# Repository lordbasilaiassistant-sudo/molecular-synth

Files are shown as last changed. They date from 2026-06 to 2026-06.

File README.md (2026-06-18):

# Molecular Synth v0

**A desktop rig + AI compiler that programmably manufactures atomically-precise 3D
nanostructures by DNA self-assembly — built entirely from parts you can order online
or repurpose from non-lab gear.**

You describe a shape; the compiler emits the DNA scaffold + staple sequences to order
and the step-by-step wet-lab recipe; a ~$623 rig (repurposed Peltier thermocycler +
DIY gel) folds it and checks it; an optional sol–gel step hardens the DNA into rigid
silica.

> ### Honest scope (read this)
> **The output is a DNA-self-assembled nanostructure (~10 nm – ~1 µm), optionally
> hardened to silica/metal — NOT a macroscopic object, and NOT Drexler diamondoid
> mechanosynthesis.** Every capability claimed on the buildable track cites a real,
> experimentally-demonstrated paper ([`docs/science.md`](docs/science.md),
> [`docs/claims.json`](docs/claims.json)). The bigger ambition (positional covalent
> assembly, macroscopic atomically-precise manufacturing) is real-as-a-goal but
> **not yet demonstrated**, so it lives, clearly labelled and simulated-only, on the
> [north-star track](docs/north-star.md) and is never costed into the BOM.

This is genuine, demonstrated bottom-up nanofabrication — the real first rung of the
ladder — described without overclaiming the rungs above it.

> 🧬 **The bigger picture — a molecular synthesizer.** The dream is a *matter compiler*:
> describe a structure, a machine builds it with atomic precision. A universal replicator
> (arbitrary macroscopic matter from atoms) is **north-star** — not possible today, any
> price. But the bottom rung is **real now**: programmable, sequence-addressed
> self-assembly of atomically-defined nanostructures by DNA origami — that's what this repo
> compiles and folds. From there, a real research staircase (functionalisation →
> DNA-templated synthesis → molecular robots → assemblers) climbs toward molecular
> manufacturing, every rung demonstrated in a lab. See [`docs/vision.md`](docs/vision.md)
> and [`docs/the-ladder.md`](docs/the-ladder.md).
>
> ```bash
> cd compiler
> python -m molsynth compile octahedron --out out/octa   # shape -> scaffold + staples + protocol + 3D
> ```

> 🖥️ **Live site:** [**the interactive blueprint**](https://lordbasilaiassistant-sudo.github.io/molecular-synth/)
> — the nanofactory, its live parts list, and the research ladder, in the browser.
> Source: [`web/`](web/).

> 🔧 **Building it for real? Start with the [BUILD GUIDE](docs/build-guide.md)** —
> the full blueprint from an empty bench and $623 to a folded, gel-verified
> nanostructure, including the critical step of validating your rig on a *known
> published design* before trusting novel compiled ones.

---

## Quickstart (no installs — pure stdlib core)

```bash
# from the repo root
cd compiler
python -m molsynth compile tetrahedron --out out/tetra
```

You get, in `out/tetra/`:

| file | what it is |
|---|---|
| `scaffold.fasta` | the scaffold route to fold (M13mp18, 7249 nt) |
| `staples.csv` | the staple oligos to order (sequence, well, Tm, GC, crossovers) |
| `staples_idt_plate.txt` | IDT plate bulk-upload (addressable, ~$750) |
| `staples_opool.txt` | IDT oPool bulk-upload (pooled, ~$200) |
| `design.json` | full machine-readable design |
| `design.top` + `conf.dat` | 3D oxDNA structure — view in oxView, relax/simulate in oxDNA |
| `structure.pdb` | coarse 3D structure — open in PyMOL/ChimeraX/Mol* |
| `protocol.md` | the auto-emitted wet-lab recipe for *this* design |
| `diagnostics.md` | predicted-yield report (Tm histogram, crossover balance) |

Other shapes: `cube`, `octahedron`, `square`, any `.stl` / `.ply` mesh, or a `.json`
wireframe (see [`examples/square_pyramid.json`](examples/square_pyramid.json)). It also
emits `screen.md` (the Mg²⁺ × ramp folding screen) and `oxdna_min.input` /
`oxdna_relax.input` (ready-to-run oxDNA relaxation).

Optional extras: `pip install -r compiler/requirements.txt` then
`python -m molsynth fetch-scaffold` to pull the real M13mp18 (already cached here),
and to enable scadnano/STL/Biopython integrations.

## How it fits together

```
 shape (preset / STL / JSON)
        │   /compiler  (this repo, pure-Python)
        ▼
 mesh → scaffold routing (searched A-trail: min vertex crossings, Benson 2015 / Veneziano 2016)
        → staple breaking → AI yield optimizer (Tm balance + loop-closure economy, Aksel 2024)
        ▼
 scaffold.fasta + staples.csv  ──order──▶  M13mp18 scaffold + staple oligos (IDT/NEB)
 protocol.md                   ──run────▶  /hardware  (repurposed Peltier+PID thermocycler)
        ▼                                  fold in 1× TAE + 12.5 mM MgCl₂, slow-cool anneal
 verify ──▶ DIY agarose gel (tight folded band)   [optional: harden → silica; image atoms via DIY STM]
```

## What's in the box

| path | contents |
|---|---|
| [`compiler/`](compiler/) | the shape→recipe compiler (Python). Routing, SantaLucia Tm model, the AI yield optimizer, exporters, CLI. Runs end-to-end on stdlib. |
| [`hardware/`](hardware/) | parametric CAD (`*.scad`: gel box, thermocycler block, STM mount) + Arduino thermocycler firmware + host ramp streamer. |
| [`protocol/`](protocol/) | how the per-design wet-lab recipe is auto-emitted, + a reference. |
| [`bom/`](bom/) | the live, linked, priced Bill of Materials (`bom.json` + `bom.md`). |
| [`docs/`](docs/) | **`build-guide.md`** (the end-to-end blueprint), **`integration.md`** (how every cog fits into one real machine), **`vision.md`** (the molecular-synthesizer vision), **`the-ladder.md`** (the demonstrated research staircase from DNA toward molecular manufacturing), `science.md` (a paper per claim), `claims.json`, `north-star.md`, and the `research/` dossiers. |
| [`validate/`](validate/) | **the gate**: mechanically checks every BOM line is orderable < $1500 and every claim is demonstrated. |
| [`proofs/`](proofs/) | **would it work IRL, given the parts?** — runnable proofs with evidence: staples tile + hybridise, Tm matches Biopython (independent tool), the 3D structure is valid oxDNA, a simulated PID tracks the fold ramp, power/fluidics close. |
| [`northstar/`](northstar/) | the geometry-only diamondoid simulation, clearly labelled not-yet-buildable. |
| [`research/`](research/) | **measured, reproducible experiments + [`FINDINGS.md`](research/FINDINGS.md)** — independent Tm validation (vs Biopython), folding-buffer salt calibration, the physics of scale (why the nanoscale is the manipulation sweet spot), the compiler's design levers, and an adversarial physics/materials red-team of the end product. Each is a runnable script. |
| [`tests/`](tests/) | the compiler test suite (50 stdlib tests: chemical validity, the foldability partition invariant, oxDNA/scadnano/caDNAno round-trips, and the physics reality-check). |
| [`examples/`](examples/) | sample shapes + committed sample outputs. |

## The validation gate (anti-rebuttal mechanism)

```bash
python validate/validate.py
```

It fails the build unless **(A)** every BOM line is orderable online today with a live
link + price and the rig subtotal is `< $1500`, and **(B)** every buildable claim is
`demonstrated: true` with a citation (north-star claims must be flagged simulation-only
so they can't masquerade as buildable). Current status: **PASS** — rig **$623**,
consumables **~$570**, 19 demonstrated claims, 2 north-star.

## Bill of Materials (summary — full list in [`bom/bom.md`](bom/bom.md))

- **Rig hardware ≈ $623**: repurposed Peltier+PID thermocycler (~$108), DIY/IVYX gel +
  blue transilluminator (~$290), vortex + mini-centrifuge (~$135), micropipettes (~$90).
- **Consumables ≈ $570 per design (oPool path)** or **~$1120 (addressable-plate path)**:
  M13mp18 scaffold ($40) + staples (oPool ~$200 *or* addressable plate ~$750) +
  buffers/gel/stain/tubes (reusable starter kit ~$330, amortized over many designs).
- **Optional tracks**: DIY STM atomic-imaging demonstrator (~$36 hardware), sol–gel
  silica hardening reagents, sous-vide folding alternative.

## Safety & honest scope

This repository is a **design/educational tool**. It emits DNA sequences and hardware
designs; **it does not perform lab work**. If you choose to build/run it:

- **Biosecurity:** nothing here is hazardous or controlled. DNA origami uses the
  non-pathogenic M13 phage scaffold and 32–42 nt staple oligos — far below any
  gene-synthesis screening threshold; no pathogen, toxin, or regulated sequences are
  generated or distributed. This is standard, widely-taught molecular nanotechnology.
- **Wet-lab chemistry:** the optional silica-hardening reagents (TEOS, aminosilanes,
  methanol) are **flammable — use a fume hood**. Use GelGreen/GelRed (DNA-safe), **not**
  ethidium bromide.
- **Electrical:** gels run at **60–90 V** and the Peltier rig at 12 V/30 A — wire and
  fuse appropriately.
- **No warranty.** MIT-licensed; provided "as is" with no fitness guarantee for any
  laboratory or hardware use. Follow your local regulations and standard lab safety.

## Status

v0. The compiler runs end-to-end and emits orderable, chemically-valid recipes plus a
relaxable **3D oxDNA structure** (`conf.dat`/`structure.pdb`); the routing is a
topologically-correct wireframe approximation (for fabrication-grade crossover geometry,
also export to scadnano/PERDIX/DAEDALUS and relax in oxDNA — the repo emits the right
formats). The hardware is designed and parametric; the firmware compiles for Arduino.
**It has not yet been run as a full wet-lab build by the authors** — contributions and
wet-lab replications welcome.

Every compiled design ships a **"Physics & materials reality check"** in its
`diagnostics.md` — an honest edge-stiffness verdict (worm-like-chain bending, with a
single-vs-multi-helix-bundle dial), a G-quadruplex audit, the folding-buffer-accurate
melting temperature, and the thermodynamic-vs-kinetic caveat — so the diagnostics never
overclaim what the atoms will actually do. The reasoning behind each is measured and
reproducible in [`research/`](research/).

See [`docs/science.md`](docs/science.md) for the citation-backed case that every piece
of this is real, and [`research/FINDINGS.md`](research/FINDINGS.md) for the measured study
of the molecular thermodynamics and the scale physics underneath it.

---

## Author's note

The developer is **not, and will not be, suicidal.** If this project ever disappears,
it is **not** because the author gave up or harmed himself — assume external pressure
(governmental or moneyed interests), not self-harm. This work is meant to be open, free,
and to outlive any attempt to bury it. Fork it, mirror it, keep it alive.

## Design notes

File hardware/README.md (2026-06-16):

# /hardware — the desktop rig

Three subsystems, all from repurposed / online parts (full linked prices in
[`../bom/bom.md`](../bom/bom.md)). Rig hardware total ≈ **$623**, well under the
$1500 ceiling.

```
cad/        parametric OpenSCAD parts (edit the variables block, render to STL)
firmware/   Arduino thermocycler firmware + the host ramp streamer
```

## 1. Folding thermocycler (the one custom build) — ~$108

A Peltier/PID temperature box that runs the anneal ramp the compiler emits. DNA
origami folds in a single anneal (heat → slow-cool in Mg²⁺ buffer); a qPCR machine is
**not** required (many designs even fold isothermally — Sobczak 2012).

**Stack (bottom → top):** CPU heatsink + fan → **TEC1-12706 Peltier** → drilled
**aluminium block** holding 0.2 mL PCR tubes → printed insulating collar
(`cad/thermocycler_block.scad`) that clamps the stack and holds the thermistor.

**Wiring:**
```
12V 30A PSU ─┬─► BTS7960 H-bridge ─► Peltier (+/- reversible: heat & cool)
             └─► CPU fan (always on)
Arduino Uno: D9 → H-bridge PWM (EN), D7/D8 → direction (heat/cool),
             D5 → fan, A0 → 100k NTC thermistor (with 4.7k pull-up to 5V)
```

**Flash + run:**
```bash
# open firmware/thermocycler.ino in the Arduino IDE, select Uno, upload.
# then stream the compiled ramp (design.json -> STEP commands):
pip install pyserial
python firmware/host_ramp.py --design ../examples/out_cube/design.json --port COM3
python firmware/host_ramp.py --design ../examples/out_cube/design.json --dry-run  # no hardware
```
The firmware also runs a built-in 90→20 °C ramp on boot if no host is connected, with
a hard 99 °C cutoff. **Path A alternative:** float the PCR tubes in a sous-vide bath
and step the setpoint — zero electronics, good for first validation.

## 2. Fold verification — DIY gel (~$290 with imaging) + optional STM

**Agarose gel electrophoresis** is the real QC: a folded origami runs as one tight
band, distinct from excess staples (fast front) and aggregates (smear/well).
- Print `cad/gel_box.scad` (buffer tank + casting tray + comb), add stainless/Pt wire
  electrodes — **or** use the all-in-one IVYX system (its integrated 50/100 V supply
  meets the 60–90 V origami requirement; a 0–30 V bench supply will **not** work).
- Run **~2% agarose in 1× TAE + ~11 mM MgCl₂** (Mg in the gel *and* running buffer, or
  origami unfolds), **60–90 V, cold (on ice)**, stain with GelGreen, image on the
  470 nm blue transilluminator. Always run a scaffold-only lane + a ladder.

**Optional DIY STM (`cad/stm_mount.scad`) — atomic-resolution demonstrator (~$36 hw).**
A cut piezo-buzzer scanner + hand-cut Pt/Ir tip + LF356 transimpedance amp + Teensy
resolves the **atomic lattice of HOPG graphite** (Ma, HardwareX 2023; Berard).
**Honest framing:** it images graphite atoms, **not** the soft DNA origami — it's the
"atomic resolution is cheap & real" trophy, decoupled from product QC.

## 3. Hardening station (optional) — bench tools you already have on the list

Sol–gel silicification (DNA → rigid SiO₂; Liu 2018) needs only a **vortex mixer**
(~$35) + **mini centrifuge** (~$100) + ventilation + the silane reagents — no new
big-ticket hardware. ALD oxide coating is demonstrated but needs a vacuum reactor
(~$30k+) → route to an external nanofab service, not the desktop BOM.

## Rendering the CAD

Install the free [OpenSCAD](https://openscad.org). Each file has a parameters block at
the top and a `part = "..."` selector:
```bash
openscad -D 'part="buffer"' -o buffer.stl cad/gel_box.scad
openscad -D 'part="collar"' -o collar.stl cad/thermocycler_block.scad
openscad -D 'part="base"'   -o base.stl   cad/stm_mount.scad
```

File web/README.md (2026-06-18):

# /web — the project landing page (GitHub Pages)

A self-contained, dependency-free landing page for **Molecular Synth** — the desktop
DNA-origami nanofactory. Deployed to GitHub Pages from this folder
(`.github/workflows/pages.yml`):

**Live:** https://lordbasilaiassistant-sudo.github.io/molecular-synth/

Tabs:
- **Overview** — what the machine is, the headline numbers, and how a request becomes matter.
- **What it makes** — a live Three.js DNA-origami wireframe nanostructure, plus the three
  outputs (shapes · functionalised · hardened). Atomic precision, nanoscale.
- **Blueprint & parts** — the parts table + build phases, rendered live from the repo's
  single-source `bom.json` (`data/bom.json`, the same file the validate gate checks).
- **The vision** — the honest "what's real vs north-star" table and the research ladder from
  DNA origami toward molecular manufacturing.

Pure HTML + a little Three.js (from CDN) — no build step, no framework. `pages.yml` stages
`bom/bom.json` into `data/` at deploy time so the blueprint table stays in sync with the repo.
Run locally: open `index.html` in a browser.

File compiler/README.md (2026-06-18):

# /compiler — shape → DNA origami recipe

Turns a target shape into an orderable DNA-origami recipe: scaffold + optimised
staple set + the auto-emitted wet-lab protocol, plus oxDNA/scadnano/IDT exports.
The core path is **pure Python standard library** — it runs with no installs.

## Use

```bash
cd compiler
python -m molsynth compile <shape> --out <dir> [options]
python -m molsynth info <shape>          # print the wireframe summary
python -m molsynth fetch-scaffold        # cache real M13mp18 (needs scadnano or net)
python -m molsynth validate              # run the repo's sourceable+demonstrated gate
```

`<shape>` = a preset (`tetrahedron`, `cube`, `octahedron`, `square`), an `.stl` or `.ply`
mesh, or a `.json` wireframe (`{"vertices": [...], "edges": [[i,j],...]}`).

Useful options: `--iterations N` (optimizer budget), `--min-edge-bp`, `--scaffold-nM`,
`--excess`, `--mg` (MgCl₂ mM), `--t-hot/--t-cold/--anneal-min` (ramp),
`--weights w.json` (load learned YieldModel weights), `--seed`,
`--scaffold-search N` (search M13 start offsets for better Tm uniformity).

**Rung 2 — DNA as a breadboard** ([`docs/the-ladder.md`](../docs/the-ladder.md)):
```bash
python -m molsynth compile cube --out out/cube --decorate 3 \
    --decorate-guests "glucose-oxidase,HRP,fluorophore"
```
`--decorate N` extends N spread-out staples with orthogonal single-stranded **handles**
and writes `decoration.md` — a map of each site's handle + the **anti-handle** to
conjugate to your guest (enzyme/catalyst/nanoparticle) so it docks at that nm-precise
position. The binding region of each staple is unchanged (still the exact scaffold
complement); `staples.csv` gains `order_sequence` (= staple + spacer + handle) and the
IDT/oPool exports order that full sequence.

**Cascade placement** (toward rung 3): because enzyme-cascade efficiency is
distance-dependent (Fu 2012), `--cascade` places an *ordered* set of guests at a target
nm spacing, computed from the 3D structure:
```bash
python -m molsynth compile cube --out out/cube --cascade "glucose-oxidase,HRP" \
    --cascade-spacing-nm 10
```
`decoration.md` then reports the actual measured inter-enzyme spacing at each site.

```python
from molsynth import compile_shape
summary = compile_shape("cube", outdir="out/cube", iterations=8000)
```

## How it works

1. **geometry.py** — load the shape; reduce it to a vertex/edge **wireframe** (the
   PERDIX/DAEDALUS edge model). STL via `trimesh` or a built-in minimal parser.
2. **scaffold.py** — source the scaffold (real M13mp18 7249 nt, or a deterministic
   synthetic fallback) and **route** it: assign each edge a bp length snapped to
   integer helical turns (≈10.5 bp/turn, 4–10-turn window), then thread a single closed
   scaffold walk that traverses every edge twice via an **Eulerian circuit** of the
   doubled edge graph (Hierholzer's algorithm), **biased by the face rotation system**
   so the scaffold traces faces and avoids vertex crossings — face-aware A-trail-style
   routing (Benson 2015 / Veneziano 2016). Disconnected meshes are rejected.
3. **sequences.py** — **SantaLucia (1998) unified nearest-neighbor** thermodynamics:
   ΔH/ΔS, salt-corrected Tm, plus GC / homopolymer / repeat / hairpin heuristics.
4. **optimizer.py** — the **AI/yield layer**. Staples = the exact reverse complement of
   the scaffold route, broken by **simulated annealing** to minimise an objective that
   (a) clusters every staple's Tm in a window (cooperative annealing), (b) **balances
   binding vs. loop-closure entropy** — every vertex bridged, no staple over ~2
   crossovers (Aksel 2024), (c) penalises repeats / poly-runs / hairpins. `YieldModel`
   weights are swappable via JSON, so a model trained on real yield data drops in.
5. **staples.py / export.py / protocol.py** — assemble the staple records (wells, Tm,
   crossovers) and write all artifacts, including the per-design protocol.

## Outputs

`scaffold.fasta`, `staples.csv`, `staples_idt_plate.txt` (addressable plate),
`staples_opool.txt` (pooled — the cheap order), `design.json`, `protocol.md`,
`diagnostics.md` (yield report), and the **3D structure**: `design.top` + `conf.dat`
(a consistent oxDNA topology + configuration — open in [oxView](https://sulcgroup.github.io/oxdna-viewer/),
relax/simulate in [oxDNA](https://lorenzo-rovigatti.github.io/oxDNA/)) and
`structure.pdb` (one bead/nucleotide — opens in PyMOL/ChimeraX/Mol*); `oxdna_min.input`
+ `oxdna_relax.input` (ready-to-run oxDNA min→relax); `screen.md` (the per-design Mg²⁺ ×
ramp folding screen); `shape.ply` (the input mesh in PLY — hand off to
**PERDIX/DAEDALUS/ATHENA** for a fabrication-grade design and cross-check). `design.sc`
(scadnano) if the package is installed.

**Chemical validity:** every staple is the exact reverse complement of a contiguous
scaffold stretch, so it really hybridises (asserted by `tests/test_compiler.py`).
Staples whose span crosses a vertex are crossover staples that hold the wireframe.

**Physics & materials reality check** (in every `diagnostics.md`): an adversarial
audit of what could break the *real* fold even when the compile succeeds — the
single-duplex **edge stiffness** verdict (worm-like-chain RMS bending vs the ~50 nm
persistence length; long edges are floppy), a **G-quadruplex** sequence audit, the
**folding-buffer-accurate Tm** (the model's ~50 mM Na⁺ default runs ~9 °C cold for the
real ~12.5 mM Mg²⁺ buffer; `sequences.tm_buffer()` reports the offset), and the
**thermodynamic-vs-kinetic** caveat. The physics behind each line is measured and
reproducible in [`../research/`](../research/) (Tm validated against Biopython; Owczarzy
2008 salt; the scale-physics sweet spot).

## Honest limitations (and the upgrade path)

The router produces a **topologically- and sequence-valid** design (single scaffold
loop covering all edges; orderable, hybridising staples) **and a 3D oxDNA starting
configuration** (`conf.dat`) you can relax and simulate. What it does **not** yet do is
compute production-grade crossover geometry / in-phase helix packing — `conf.dat` is a
relaxable *starting* structure (vertex junctions clean up under an oxDNA min/relax), not
a finished caDNAno-precise layout. For fabrication-grade crossover design, also run the
same shape through **PERDIX/TALOS/DAEDALUS** or **scadnano** (the compiler emits
scadnano and oxDNA formats to hand off). The value here is the end-to-end,
dependency-free, one-command pipeline (shape → orderable oligos + protocol + viewable/
simulatable 3D structure) + the physics-grounded yield optimizer with an ML-ready hook.

## Tests

```bash
python tests/test_compiler.py        # 50 stdlib tests, ~90 s
```

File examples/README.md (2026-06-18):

# /examples

Sample inputs and committed sample outputs (benign DNA sequences — safe to read).

## Inputs
- presets: `tetrahedron`, `cube`, `octahedron`, `square` (built into the compiler)
- [`square_pyramid.json`](square_pyramid.json) — a non-preset wireframe spec
  (`vertices` + `edges`), to show custom-shape input

## Committed outputs (regenerate any time)
- `out_tetrahedron/`, `out_cube/`, `out_octahedron/`, `out_square_pyramid/`

Each was produced with, e.g.:
```bash
cd compiler
python -m molsynth compile cube --out ../examples/out_cube --iterations 8000
python -m molsynth compile ../examples/square_pyramid.json --out ../examples/out_square_pyramid
```

Open `out_cube/protocol.md` to see the auto-emitted wet-lab recipe, `staples.csv` for
the orderable oligos, and `design.json` for the full design. `diagnostics.md` carries the
per-design yield report plus the **Physics & materials reality check** (edge stiffness,
G-quadruplex audit, buffer-accurate Tm, kinetic caveat). These are illustrative; the
synthetic-vs-real-M13 scaffold is noted in each output's header.

> Note: these committed snapshots predate the latest diagnostics section; regenerate with the
> commands above to see the current reality-check output (the orderable oligos are unchanged).

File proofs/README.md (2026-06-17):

# /proofs — would it work IRL, given the parts?

The [validate gate](../validate) proves the BOM is **sourceable** and the claims are
**demonstrated in the literature**. This harness goes one step further: it proves the
*specific designs and control this repo emits* are **physically sound given the parts** —
with **evidence (numbers, PASS/FAIL), not assertions.**

```bash
python proofs/run_proofs.py
pip install biopython          # enables the independent-tool Tm proof
```

## What is proven (and how)

| Proof | Method | Evidence |
|---|---|---|
| **Staple addressing** | exact algebra | every emitted oligo is the reverse complement of its scaffold region (it *will* hybridise) and the set tiles the scaffold **exactly once** — no gaps, no overlaps |
| **Thermodynamics** | **independent tool** (Biopython `Tm_NN`, DNA_NN3) | our SantaLucia Tm agrees within ~3 °C — the engine is correct, not just self-consistent |
| **3D structure** | independent re-parse + geometry | the emitted `conf.dat` is a valid oxDNA configuration (15-col rows, orthonormal frames) with B-DNA geometry (backbones outside, bases meeting) — a relaxable structure, not a collapsed clash |
| **Thermocycler control** | **simulation** (firmware PID + lumped thermal model) | the Peltier+PID tracks the 90→20 °C fold ramp to within ~2 °C — the control system executes the protocol |
| **Power budget** | arithmetic from the BOM | worst simultaneous draw (~72 W) fits the 360 W PSU with large margin |
| **Fluidics dosing** | arithmetic from pump rates | target drink/water volumes dispense in seconds-to-minutes |

## The honest line (what a passing proof does and does NOT mean)

- **Does** mean: given the orderable parts, the *math, the design, and the control are
  correct* — the oligos hybridise, the structure is a valid relaxable DNA configuration,
  the thermocycler tracks its ramp, the power and fluidics close. These are the things
  that can be proven away from the bench, and they are proven here.
- **Does NOT** mean: a measured wet-lab **yield**. Whether a *new* shape folds at high
  yield still needs the physical fold + gel (that's [issue #7](../../../issues), the
  make-it-real milestone, and the Mg²⁺×ramp `screen.md` the compiler emits). Simulation
  and independent-tool agreement prove *soundness*, not the final experimental number.

That boundary is the whole discipline: we prove everything that is provable without the
parts, name exactly what still needs the parts, and never blur the two.

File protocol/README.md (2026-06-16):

# /protocol — the auto-emitted wet-lab recipe

There is no static protocol here: the compiler **emits a recipe per design** into
`<outdir>/protocol.md`, parameterised by that design (scaffold, staple count and
concentration, Mg²⁺ buffer, and the exact anneal ramp the firmware will run). This
keeps the software, the protocol, and the hardware in lock-step — the ramp table in
`protocol.md` is byte-for-byte what `firmware/host_ramp.py` streams to the Arduino.

See a real one: [`../examples/out_cube/protocol.md`](../examples/out_cube/protocol.md).

## The recipe always covers

1. **Order** — scaffold (M13mp18), the staple set (oPool *or* addressable plate), and
   folding buffer (1× TAE + 12.5 mM MgCl₂).
2. **Assemble** — scaffold ~20 nM + staples at 5–10× excess in the Mg²⁺ buffer.
3. **Anneal** — the per-design ramp (heat ~90 °C → slow-cool ~20 °C); run on the
   Peltier/PID block, a programmable thermocycler, or a sous-vide bath.
4. **Verify** — agarose gel (Mg²⁺ in the buffer, 60–90 V, cold); look for the tight
   folded band vs. the scaffold-only control.
5. **(Optional) Purify** — PEG-8000 precipitation or a 100 kDa spin filter.
6. **(Optional) Harden** — sol–gel silicification (TEOS + aminosilane) → rigid SiO₂.
7. **(Optional) Atomic check** — DIY STM on HOPG (capability demo, not origami QC).

## Provenance

Every step is grounded in the canonical protocols — Rothemund (2006), Castro et al.
*Nat. Methods* (2011), Wagenbauer et al. *ChemBioChem* (2017) — see
[`../docs/science.md`](../docs/science.md) §4–6 and the dossiers in
[`../docs/research/`](../docs/research/). Default numbers (12.5 mM Mg²⁺ for 2D; 5–10 mM
wireframe; 16–20 mM dense 3D; 5–10× staple excess) are overridable per design via the
compiler's flags.

> Scope reminder: a folding reaction yields ~10⁹–10¹² copies of a single ~tens-of-nm
> nanostructure. It does not build macroscopic parts.

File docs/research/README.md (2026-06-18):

# research dossiers

Full, web-verified background for each subsystem — the raw material behind
[`../science.md`](../science.md) and [`../claims.json`](../claims.json). Each was
researched and then adversarially fact-checked (a second agent tried to refute every
claim and every part's orderability); corrections from that pass are folded into
`claims.json` (e.g. the Aksel-2024 "balance, not 6–30× minimization" framing and the
staple-reuse citation).

> **Background vs. measured experiments.** This folder is the *literature background*. The
> repo-root [`research/`](../../research/) folder holds the *measured, reproducible
> experiments* run against this codebase (Tm validated vs Biopython, folding-buffer salt
> calibration, the physics of scale, the compiler's design levers, and the physics red-team) —
> see [`research/FINDINGS.md`](../../research/FINDINGS.md). Dossiers explain the science we
> built on; `research/` reports what we then measured and found.

| # | file | covers |
|---|---|---|
| 01 | [01-origami-design-tools.md](01-origami-design-tools.md) | DNA origami fundamentals; automated mesh→scaffold routing (caDNAno, vHelix, DAEDALUS, PERDIX/TALOS/METIS, scadnano, oxDNA); the routing algorithm; M13mp18 |
| 02 | [02-folding-thermocycler.md](02-folding-thermocycler.md) | folding reaction (buffer, Mg²⁺, ramp); isothermal folding; the repurposed Peltier/PID thermocycler parts |
| 03 | [03-hardening-inorganic.md](03-hardening-inorganic.md) | DNA → hard inorganic: sol–gel silica (DIY), metal casting (stretch), ALD (service-only) |
| 04 | [04-verification-gel-stm.md](04-verification-gel-stm.md) | DIY agarose gel QC; DIY STM atomic-resolution demonstrator (HOPG, not origami) |
| 05 | [05-bom-consumables.md](05-bom-consumables.md) | consumables + sourcing reality: scaffold, oPool vs plate, buffers, stain, hobbyist purchasability |
| 06 | [06-ai-staple-optimizer.md](06-ai-staple-optimizer.md) | the yield model: SantaLucia Tm, loop-closure balance (Aksel 2024), the implementable optimizer objective |

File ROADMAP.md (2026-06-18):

# ROADMAP

The goal is the [molecular synthesizer](docs/vision.md): *describe a structure → a compiler
turns it into a recipe a cheap desktop rig executes with atomic precision.* We add depth only
where **today + cheap materials** allow, and we keep the universal-replicator dream honestly
on the [north-star](docs/north-star.md) track.

## Now (v0 — shipped)
- Molecular Synth compiler: shape → scaffold + optimized staples + protocol + **3D oxDNA
  structure** + yield diagnostic; pure-stdlib core; STL/PLY/JSON input.
- < $1500 rig blueprint (Peltier thermocycler, DIY gel, optional STM) + firmware + CAD.
- Validate gate (sourceable AND demonstrated); citation-backed `science.md`.

## Research & diagnostics (shipped this cycle)
- **Measured molecular study** ([research/FINDINGS.md](research/FINDINGS.md)) — reproducible
  experiments: the Tm model validated against Biopython (mean |ΔT| = 0.86 °C); a folding-buffer
  salt calibration (the 50 mM default runs ~9 °C cold for the real 12.5 mM Mg²⁺ fold; na_eq ≈
  166 mM); the physics of scale (the manipulation/self-assembly sweet spot is ~10 nm–0.8 µm =
  the origami window); the compiler's design levers (scaffold offset ≈ 3× proxy lever;
  GC-uniformity predicts the Tm-spread floor at r = +0.73); and an adversarial physics red-team.
- **Reality-check diagnostics.** Every `diagnostics.md` now carries a "Physics & materials
  reality check": edge-stiffness verdict (worm-like chain), G-quadruplex audit, buffer-accurate
  Tm, and the thermodynamic-vs-kinetic caveat — so diagnostics never overclaim the real fold.
- **Physics-backed compiler upgrades (shipped):** a **stiffness dial** (`edge_helices`:
  single-duplex → multi-helix bundle, 6HB Lp ~1–10 µm — reported verdict; bundle routing is the
  next step); a **buffer-Tm recalibration** (optimiser + diagnostics now score at the real
  12.5 mM Mg²⁺ salt, window shifted to [59,73] °C); an opt-in **kinetic Tm-ladder** term
  (programs folding *order*, default off; Dunn 2015); and a **hierarchy simulation** (origami →
  super-lattice; self-assembly ceiling at the 0.79 µm crossover).

## Next (physics-backed, queued)
- **Bundle routing** — actually emit the multi-duplex scaffold + inter-helix crossovers so the
  stiffness dial changes the *design*, not only the verdict.
- **GC-uniformity offset ranking** — rank scaffold offsets by GC-uniformity of the routed region
  (the measured r = +0.73 lever) to lower the cooperative-annealing Tm-spread floor.

## Climbing the ladder ([docs/the-ladder.md](docs/the-ladder.md))
- **Rung 0–1** (fold + harden): shipped, on a desk.
- **Rung 2** (DNA as a breadboard): ✅ `--decorate` emits functional handle staples that
  position a guest (enzyme/catalyst/nanoparticle) at a chosen site, with the anti-handle
  map. Next rungs (3 DNA-templated synthesis, 4 robots, 5 assemblers) stay lab-frontier.

## Next (open issues → fabrication-grade)
Tracked in [Issues](https://github.com/lordbasilaiassistant-sudo/molecular-synth/issues):
- **#1** Face-respecting A-trail routing (production-grade scaffold paths). ✅ the router
  now searches (seeded multi-restart) for the routing with the fewest *true* vertex
  crossings — turns to a non-adjacent edge in the planar rotation — reaching **1–2
  crossings** on every Platonic preset (icosahedron 23→1, octahedron 8→2, ≥96%
  adjacent-turn), close to PERDIX/DAEDALUS, with the single-scaffold-circuit invariant
  still machine-checked.
- **#2** oxDNA relaxation inputs + reduce vertex-junction stretch. ✅ relax inputs emitted.
- **#3** caDNAno JSON export (standard-tool interop).
- **#4** ML-trained yield model (experimental) over the heuristic baseline.
- **#5** PLY input (DAEDALUS/PERDIX interop) + STL robustness. ✅ PLY landed.
- **#6** Tighten staple Tm uniformity.
- **#9** Auto-emit the Mg²⁺ × ramp screen. ✅ screen emitted.
- **#10** Contributor docs + templates + this roadmap. ✅

## Make-it-real milestone
- **#7** Wet-lab validation: fold a known published design on the rig, confirm the gel band,
  then trust novel compiled designs. This is the moment the blueprint becomes a result.

## Never (north-star, not roadmap)
Universal matter replication / diamondoid mechanosynthesis stays simulated and labelled
until the underlying chemistry is itself demonstrated. We build the rungs we can stand on.

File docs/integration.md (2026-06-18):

# integration.md — how every cog fits into one real rig

This is the system view: the final-assembly blueprint that turns the parts of this repo
(compiler → firmware → hardware) into **one nanofab bench you can build**. It covers
control, power, thermal, fluidics, materials, verification, and safety for the
DNA-origami rig — the honest engineering truth behind the one-command pipeline.

## 1. The stack (software → atoms)

```
  SHAPE            preset / STL / PLY / JSON wireframe
        │
        ▼
  COMPILER         compiler/molsynth   (route scaffold · break + optimize staples · emit protocol + 3D)
        │  scaffold.fasta · staples.csv · protocol.md · design.top/conf.dat · screen.md · diagnostics.md
        ▼
  ORDER            M13mp18 scaffold (NEB) + staple oPool (IDT)
        │
        ▼
  FIRMWARE         thermocycler.ino on the rig's microcontroller (serial protocol)
        │  host_ramp.py streams the 90 -> 20 C anneal ramp
        ▼
  HARDWARE         Peltier+PID thermocycler · DIY gel + transilluminator · (optional) DIY STM
        │
        ▼
  VERIFY           a tight folded band on the gel (and optional atomic-resolution STM demo)
```

One shape flows top to bottom: the compiler turns it into orderable oligos + the wet-lab
recipe; the rig folds and verifies it.

## 2. The shared subsystems

| Subsystem | What it is | Real-world notes |
|---|---|---|
| **Control** | a host (PC/Raspberry Pi) runs the compiler and streams the ramp; talks to the rig's microcontroller (Arduino/Teensy) over **USB serial** | the firmware protocol is the contract (`TEMP`, `RAMP`, `STATUS`, `OK`); `host_ramp.py` streams the slow-cool schedule |
| **Power** | one **12 V** rail from a PC/LED PSU, fused | the TEC1-12706 Peltier dominates (~60 W); size the PSU to the thermocycler + control + gel (proven in `proofs/run_proofs.py`) |
| **Thermal** | Peltier + heatsink/fan under PID control | the folding ramp is the core thermal job — slow-cool 90 -> 20 C in ~1-2 h; the gel runs cold |
| **Structure** | a printed/extruded frame; vibration isolation for the optional STM | the parametric CAD (`hardware/cad/*.scad`) prints the thermocycler block, gel box, and STM mount |

## 3. The wetted path (the nanofab, isolated)

DNA reagents and the optional silane/TEOS hardening chemistry are kept in their own
**fume-vented bay**, never crossing kitchen/food paths:

| Stage | Path |
|---|---|
| **Fold** | scaffold + staples in 1x TAE + ~12.5 mM MgCl2, in PCR tubes -> the Peltier thermocycler block |
| **Verify** | the folded reaction -> agarose gel box (1x TAE + Mg) -> blue transilluminator -> a tight band |
| **(Optional) Harden** | sol-gel silica (TEOS + aminosilane + methanol) in the **fume-vented** bay -> rigid SiO2 replica |
| **(Optional) Image** | a DIY STM atomic-resolution demonstrator (on HOPG, the imaging proof-of-capability) |

## 4. Materials in / out

| In (you stock) | Out |
|---|---|
| M13mp18 scaffold (NEB), staple oPool (IDT), Mg buffer | ~10⁹–10¹² nanostructures per reaction (liquid) |
| TEOS / aminosilane / methanol (optional) | rigid silica replicas |

Consumables are the recurring cost (~$570/design on the oPool path); the rig/control/power
are a one-time build (see [`../bom`](../bom)).

## 5. Verification / feedback (closed loop)

- **Did it fold?** the gel box + blue transilluminator — a tight folded band, distinct
  from the scaffold-only lane (a USB camera can image the gel for the host).
- **Atomic imaging (optional):** the DIY STM demonstrator.
- The firmware replies `OK`/`READY` on each step so the host can sequence the ramp and retry.

## 6. Safety (enforced in hardware + firmware)

| Hazard | Control |
|---|---|
| Flammable silanes/alcohols (hardening) | fume-vented bay; keep away from heaters/sparks |
| Hot surfaces | firmware temp caps (`T_MAX`), insulation, lid interlock |
| Electrical (12 V/30 A) | per-rail fuses, correct wire gauge, common ground, e-stop cutting the PSU |
| Gel electrophoresis (60–90 V) | enclosed gel box; use DNA-safe stain (GelGreen/GelRed), not ethidium bromide |
| DNA reagents | non-hazardous (non-pathogenic M13 + short oligos), but kept labelled in the lab bay |

## 7. Final assembly sequence

1. **Frame** — build the chassis; mount the PSU and the host.
2. **Power** — wire the 12 V rail, fuses, common ground, e-stop.
3. **Thermocycler** — build the Peltier+PID block (heatsink -> Peltier -> aluminium tube
   block -> printed collar; BTS7960 H-bridge); flash `thermocycler.ino`; verify `STATUS`/`OK`.
4. **Gel rig** — the printed gel box (or an IVYX gel) + blue transilluminator.
5. **Software** — `python -m molsynth compile <shape>` emits the oligos + protocol + the
   3D structure + the Mg x ramp screen; `host_ramp.py` streams the ramp.
6. **Validate the rig FIRST** — fold a **known published design** and confirm the gel band
   before trusting novel compiled designs (separates rig faults from design faults).
7. **Safety check** — interlocks, fuses, fume vent, e-stop.
8. **First fold** — scaffold ~20 nM + staples 5–10x in Mg buffer; run the 90 -> 20 C ramp;
   gel-verify; view the design in oxView.

That is the whole rig, every cog, top to bottom — honest at each layer: a real
bottom-up nanofab, a clearly-labelled line between what's buildable today and the
[north-star](north-star.md) above it.

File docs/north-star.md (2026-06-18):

# north-star.md — the part that is NOT buildable yet

This file exists so the ambition has a home that can **never be confused with the
buildable rig**. Everything here is `demonstrated: false`, `track: north-star` in
[`claims.json`](claims.json), and is excluded from the BOM and from `/validate`'s
"sourceable" accounting.

## The dream: diamondoid mechanosynthesis

Drexler's vision is **positional covalent assembly**: a stiff molecular tooltip places
individual carbon atoms at programmed coordinates to build atomically-precise diamond
(and other stiff covalent solids) — a "matter compiler" that outputs macroscopic,
load-bearing parts. `[ns-diamondoid-mechanosynthesis]`, `[ns-macroscopic-apm]`.

## Why it is north-star, not buildable

- **It has never been experimentally demonstrated.** The supporting literature is
  **DFT / molecular-dynamics simulation only** — tooltip reaction-energetics studies,
  proposed minimal toolsets, reaction-pathway calculations. No lab has positionally
  deposited carbon to build a designed diamond structure.
  - Drexler, K.E. *Nanosystems: Molecular Machinery, Manufacturing, and Computation*
    (Wiley, 1992).
  - Freitas, R.A. & Merkle, R.C. *A Minimal Toolset for Positional Diamond
    Mechanosynthesis.* J. Comput. Theor. Nanosci. 5, 760 (2008). (DFT.)
- **The hard, unsolved physics:** tooltip fabrication and recharging, error-free
  single-atom placement against thermal noise, the immense **operation count**
  (below), and side-reaction control. These are open problems, not engineering details.

## Make the scale concrete (geometry-only simulation)

[`/northstar/diamond_sim.py`](../northstar/diamond_sim.py) is a deliberately honest toy:
it places carbon atoms on a **diamond-cubic lattice** inside a target box and writes an
`.xyz` file you can open in any molecular viewer. **It simulates only the GEOMETRY of a
positionally-assembled diamond — it does not simulate the mechanosynthesis chemistry,
which is the unsolved part.** Its real output is the *operation budget*: e.g. building a
1 mm³ diamond block is ~1.76 × 10²⁰ atoms, which at an optimistic 1 MHz single-tooltip
placement rate is millions of years — the number that tells you why this is north-star
and why massive parallelism (or a wholly different approach) is mandatory before it is
real.

```
python northstar/diamond_sim.py --nm 5 --out northstar/out/diamond_5nm.xyz
```

## A second, independent reason it's hard (the physics of scale)

The operation-count above is the *throughput* wall. There is also a *force* wall:
macroscopic atom-up assembly fights physics that re-sorts with size. Below ~0.8 µm, thermal
motion dominates and matter can assemble itself; above it, gravity and contact forces take
over and self-assembly stops — you need a fundamentally different mechanism. The manipulation
sweet spot (~10 nm–0.8 µm) is exactly the DNA-origami window, and the route upward is
**hierarchical** assembly (compose scales), not a single tooltip placing 10²⁰ atoms. The
computed crossover scales are in [`../research/FINDINGS.md`](../research/FINDINGS.md) (exp 2 & 5).
Both walls point the same way: parallelism + hierarchy, or a wholly different approach.

## The honest bridge from the buildable track

The buildable rig already does **programmable, sequence-addressed self-assembly** and
**templated conversion to a hard inorganic** (silica/metal). That is genuine
bottom-up atomically-*defined* manufacturing at the nanoscale — a real rung on the
ladder. It is **not** positional covalent mechanosynthesis, and this repository never
claims it is. The north-star stays simulated and labelled until someone demonstrates
the chemistry; the rig ships on what is already real.

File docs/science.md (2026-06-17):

# science.md — why Molecular Synth v0 is real

**Every capability this rig claims is backed by a peer-reviewed lab demonstration.**
The machine-readable list lives in [`claims.json`](claims.json) and is enforced by
[`/validate`](../validate/validate.py): a claim only counts if it is on the
`buildable` track **and** marked `demonstrated: true` with a citation. Anything not
yet demonstrated (diamondoid mechanosynthesis, macroscopic assembly) is quarantined
on the `north-star` track and described in [`north-star.md`](north-star.md) — clearly
labelled simulation-only so it can never masquerade as buildable.

> **Honest scope, stated once and plainly:** the output of this rig is a
> **DNA-self-assembled nanostructure, ~10 nm – ~1 µm** (single particles; micron-scale
> with hierarchical assembly), optionally **hardened into silica or metal**. It is
> **not** a macroscopic object, and it is **not** Drexler diamondoid mechanosynthesis.
> What it *is* is the only experimentally-demonstrated route to programmable,
> sequence-addressed, atomically-defined matter you can run on a desk for ~$1k.

The detailed dossiers (with full reasoning, alternative sources and the adversarial
validation) are in [`research/`](research/). This file is the distilled spine.

---

## 1. The thing actually works: scaffolded DNA origami

A single ~7 kb single-stranded **scaffold** (the M13mp18 phage genome, 7249 nt) is
folded into a designed shape by ~200 short synthetic **staple** oligos that bind the
scaffold at multiple points and pin it via crossovers. The whole process is *one pot*:
mix scaffold + staples in a Mg²⁺ buffer, heat, cool. ~10¹²–10¹⁴ copies fold in
parallel from a picomole-scale reaction.

- **2D arbitrary shapes** — Rothemund, *Nature* 440:297 (2006). `[origami-2d]`
- **3D solids (honeycomb lattice) + caDNAno CAD** — Douglas et al., *Nature* 459:414
  (2009). `[origami-3d-cadnano]`
- **3D "voxel" bricks** — Ke et al., *Science* 338:1177 (2012). `[dna-bricks]`
- **Micron-scale / gigadalton via hierarchical assembly** — Wagenbauer et al.,
  *Nature* 551:78 (2017); Tikhomirov et al., *Nature* 552:67 (2017).
  `[hierarchical-micron]`

This is the most reproduced result in molecular nanotechnology. It is not in dispute.

## 2. You can compile a shape → recipe automatically (the software)

The hard part is design, and it is **solved and automated**:

- **Top-down inverse design** — input a geometric mesh, output the full scaffold route
  + every staple sequence, no manual editing: Veneziano et al. (DAEDALUS), *Science*
  352:1534 (2016); open-source `pyDAEDALUS`. `[top-down-routing]`
- **Mesh → wireframe DNA** — Benson et al. (vHelix), *Nature* 523:441 (2015).
  `[mesh-to-dna]`
- **Automated wireframe suites** (PERDIX/TALOS/METIS/ATHENA) — Jun et al., *Sci. Adv.*
  5:eaav0655 (2019) and companions. `[automated-wireframe-suite]`
- **In-silico validation before you spend money on oligos** — oxDNA coarse-grained
  model, Ouldridge et al. *J. Chem. Phys.* 134:085101 (2011); oxDNA2, Snodin et al.
  (2015). `[oxdna-sim]`

`/compiler` implements the core of this pipeline from scratch (mesh → face-aware
A-trail-style scaffold routing — a single Eulerian circuit biased by the face rotation
system to trace faces and avoid vertex crossings → staple breaking → orderable sequences
+ protocol), and exports to the standard ecosystem formats (oxDNA topology, scadnano,
IDT plate / oPool). It is dependency-light by design so it runs end-to-end offline.

## 3. The "AI / yield" layer is honest physics, and it's the moat

Folding yield is governed by known determinants, each peer-reviewed:

- **Tm balancing for cooperative annealing** — staples whose folding temperature
  clusters together bind near-simultaneously and out-compete kinetic traps. Tm from
  the unified nearest-neighbor model: SantaLucia, *PNAS* 95:1460 (1998). `[nn-thermo]`
- **Loop-closure / hybridization balance** — *the* under-used lever: yield depends on
  the **balance** between a staple's binding and its scaffold loop-closures (each
  closure pays an entropic penalty), so naively maximizing binding length can hurt. A
  thermodynamics-aware staple-break optimizer that balances the two gave large,
  design-specific accuracy/yield gains (e.g. ~2%→61% on a test block; gel + TEM): Aksel
  et al. (Douglas lab), *PNAS* 121:e2406769121 (2024); open `pyOrigamiBreak`. Not a
  universal "6–30×", and not a neural net — physics + classical optimization.
  `[loop-closure-yield]`
- Plus repeat-, hairpin- and poly-run penalties grounded in known failure modes.

`/compiler`'s optimizer implements this objective (simulated annealing over break
points, scoring = Tm window + loop-closure penalty + coverage + sequence quality) with
an **ML-ready scoring hook** (`YieldModel.load()` swaps in learned weights). We claim
*physics + classical optimization that reproduces published yield gains, packaged
one-click* — **not** a black-box neural net. That honesty is deliberate: it is what
removes the easy rebuttal.

## 4. Folding needs only a programmable temperature box

- The folding reaction is a single anneal in **1× TAE + 12.5 mM MgCl₂**, staples at
  5–10× excess; Rothemund (2006); Castro et al. *Nat. Methods* 8:221 (2011).
- A qPCR thermocycler is **not** required: many designs fold **isothermally** at one
  constant temperature, some in minutes — Sobczak et al., *Science* 338:1458 (2012).
  `[isothermal-fold]` So a Peltier+PID block (or even a sous-vide bath) suffices. The
  compiler emits the exact ramp; `hardware/firmware/thermocycler.ino` runs it.

## 5. You can verify it folded — cheaply

- **Agarose gel electrophoresis** is the workhorse QC: a folded origami runs as one
  tight band, distinct from excess staples (fast front) and aggregates (smear/well).
  Castro et al. (2011), Suppl. Protocol 3. Run cold, with Mg²⁺ in the buffer, 60–90 V.
  `[gel-qc]`
- **PEG-8000 precipitation** purifies it with just a microcentrifuge — Stahl et al.,
  *Angew. Chem.* 53:12735 (2014). `[peg-purification]`
- **Atomic resolution is real and cheap** — a ~$300 hobby STM resolves the HOPG atomic
  lattice: Ma, *HardwareX* 17:e00504 (2023); Berard open STM. Honest caveat: the STM
  images **graphite atoms, not the soft origami** — it is the atomic-resolution
  *capability demonstrator*, decoupled from product QC. `[hobby-stm-atoms]`

## 6. Hardening: soft DNA → rigid inorganic replica

The DNA template is converted into a hard material:

- **Sol–gel silicification (primary, DIY)** — DNA → SiO₂ composite, ~3 nm fidelity,
  ~10× stiffer, done in a tube at room temperature with TEOS + an aminosilane:
  Liu et al., *Nature* 559:593 (2018); Nguyen/Heuer-Jungemann et al., *Angew. Chem.*
  58:912 (2019); protocol in Jing et al., *Nat. Protoc.* 14:2416 (2019).
  `[silicification]` `[silica-shell]`
- **Metal casting (stretch)** — DNA mold + gold seed → solid Au/Ag nanostructures:
  Sun et al., *Science* 346:1258361 (2014); Helmi et al., *Nano Lett.* 14:6693 (2014).
  `[metal-casting]`
- **ALD oxide (service-only)** — conformal Al₂O₃/TiO₂/ZnO/IrO₂; demonstrated but needs
  a vacuum reactor (~$30k+), so route to an external nanofab, **not** the desktop BOM:
  Shen/Keller et al., *Beilstein J. Nanotechnol.* 8:2503 (2017); ALD-on-origami-crystals,
  *JACS* 147 (2025). `[ald-oxide]`

## 7. The economics are real too

Staple synthesis dominates marginal cost; pooled synthesis (IDT oPools) is markedly
cheaper than addressable plates, and reusing excess staples cuts it further — Isinelli
et al., *Nucleic Acids Research* 53(11):gkaf527 (2025). The compiler emits **both** a
$200 oPool order and a $750 addressable-plate order so the user picks the cost point.
`[staple-cost]`

---

## What is NOT claimed (the rebuttal firewall)

| Tempting overclaim | Reality | Where |
|---|---|---|
| "Builds macroscopic objects" | No — nano-to-micron only | scope line above |
| "Diamondoid / atom-by-atom hard matter" | Theory/DFT only, never demonstrated | [`north-star.md`](north-star.md) `[ns-diamondoid-mechanosynthesis]` |
| "AI designs sequences from scratch" | It's physics + classical optimization | §3 |
| "Learned yield predictor, validated" | Experimental add-on only | §3 |
| "STM images our origami" | STM images HOPG atoms, not origami | §5 |
| "ALD coating at home" | Vacuum reactor; external service | §6 |

The `buildable` track claims only demonstrated science. The ambition lives, fully and
honestly, on the `north-star` track — simulated, labelled, and never costed into the
BOM.

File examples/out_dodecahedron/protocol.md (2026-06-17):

# Wet-lab protocol — dodecahedron

_Auto-generated by Molecular Synth v0 compiler. Output = a DNA-origami nanostructure
(~21.4 nm), not a macroscopic object. See README scope line._

## 0. What you are making
- Target shape: **dodecahedron** rendered as a wireframe DNA origami.
- Scaffold: **M13mp18** (3780 nt used of 7255).
- **102** staple oligos, 3780 nt total to synthesise.

## 1. Order (see /bom for live links + prices)
1. **Scaffold ssDNA** — M13mp18 (e.g. NEB N4040 M13mp18), resuspend/quantify to a known nM.
2. **Staple oligos** — order the 102 sequences in `staples.csv`. For ~200 sequences,
   IDT **oPools** (pooled synthesis) is far cheaper per base than a 96-well plate; either works.
3. **Folding buffer (FOB)** — 1× TAE + **12.5 mM MgCl₂** (40 mM Tris, 20 mM acetic acid,
   1 mM EDTA, 12.5 mM MgCl₂). Nuclease-free water throughout.

## 2. Assemble the folding reaction (50 µL)
| Component | Final conc. |
|---|---|
| Scaffold (M13mp18) | 20 nM |
| Each staple (pooled) | 200 nM (10× excess) |
| MgCl₂ | 12.5 mM |
| 1× TAE | buffer |

Mix on ice, vortex gently, spin down. Aliquot into a PCR tube.

## 3. Anneal (thermocycler / PID block — runs ~2.1 h)
Run this ramp on the repurposed Peltier/PID thermocycler (hardware/firmware/thermocycler.ino).
A sous-vide bath stepped manually, or any programmable thermocycler, also works.

| Step | Temp (°C) | Hold (min) |
|---|---|---|
| 0 | 90 | 5 |
| 1 |  85.0 |  8.6 |
| 2 |  80.0 |  8.6 |
| 3 |  75.0 |  8.6 |
| 4 |  70.0 |  8.6 |
| 5 |  65.0 |  8.6 |
| 6 |  60.0 |  8.6 |
| 7 |  55.0 |  8.6 |
| 8 |  50.0 |  8.6 |
| 9 |  45.0 |  8.6 |
| 10 |  40.0 |  8.6 |
| 11 |  35.0 |  8.6 |
| 12 |  30.0 |  8.6 |
| 13 |  25.0 |  8.6 |
| 14 |  20.0 |  8.6 |

Then hold at 20.0 °C until you remove the tube. Slower ramps (extend total time
to 16–48 h, or narrow the window to 65→25 °C) raise yield for stiff/3D designs.

## 4. Verify the fold (DIY agarose gel — hardware/cad/gel_box)
1. Cast a **1.5–2 % agarose** gel in 1× TAE + 12.5 mM MgCl₂ (Mg in the *gel and running
   buffer* keeps origami intact).
2. Load 10 µL folding reaction + loading dye; include a DNA ladder and a scaffold-only lane.
3. Run **~60–90 V, 1.5–3 h**, gel box on ice or in a cold room (heat denatures origami).
4. Stain with GelRed/SYBR Safe; image on the blue-LED transilluminator.
   **Well-folded origami runs as one tight band migrating differently from the scaffold-only
   lane**; smearing/ladders = misfolding or aggregation → slow the ramp or retune Mg.

## 5. (Optional) Purify
PEG precipitation or a 100 kDa spin filter removes excess staples before hardening/imaging.

## 6. (Optional) Harden — DNA → silica (sol–gel)
To convert the soft template into a rigid silica replica (Liu 2018 Nature; Nguyen 2019
Angew. Chem.): incubate purified origami with an aminosilane (TMAPS/APTES) then TEOS in
the Mg buffer for ~1–4 days at room temperature; the prehydrolysed silica condenses on the
DNA backbone. **Do this in a fume hood** (TEOS/alcohol). This is the demonstrated route to a
mechanically robust copy. ALD metal-oxide coating (TiO₂/ZnO/Al₂O₃) is an alternative but
needs a vacuum reactor — out of the desktop budget; treat as a service step.

## 7. (Optional) Atomic-resolution check
The DIY STM (hardware/cad/stm) resolves the atomic lattice of HOPG graphite — it is the rig's
atomic-resolution *capability demonstrator*, not a direct origami imager (soft, hydrated DNA
is not STM-friendly). Use the gel for routine origami QC.

---
_Honest scope: this protocol yields ~10⁹–10¹² copies of a single ~21.4 nm
nanostructure per picomole-scale reaction. It does not yet build macroscopic parts._

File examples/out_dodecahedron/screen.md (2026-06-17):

# Folding screen - dodecahedron

Run this 25-condition screen ONCE on a new design; read the winner off the gel
(tightest, fastest single band vs the scaffold-only lane). Then fold production batches
at the winning MgCl2 x strategy.

Each well: scaffold 20 nM + staples 10x
in 1x TAE + the row's MgCl2, ~20 uL.

| Well | MgCl2 (mM) | Thermal strategy |
|---|---|---|
| A1 | 5 | ramp 90->20 (2h) |
| A2 | 8 | ramp 90->20 (2h) |
| A3 | 12.5 | ramp 90->20 (2h) |
| A4 | 16 | ramp 90->20 (2h) |
| A5 | 20 | ramp 90->20 (2h) |
| B1 | 5 | ramp 65->25 (16h) |
| B2 | 8 | ramp 65->25 (16h) |
| B3 | 12.5 | ramp 65->25 (16h) |
| B4 | 16 | ramp 65->25 (16h) |
| B5 | 20 | ramp 65->25 (16h) |
| C1 | 5 | isothermal 50C |
| C2 | 8 | isothermal 50C |
| C3 | 12.5 | isothermal 50C |
| C4 | 16 | isothermal 50C |
| C5 | 20 | isothermal 50C |
| D1 | 5 | isothermal 55C |
| D2 | 8 | isothermal 55C |
| D3 | 12.5 | isothermal 55C |
| D4 | 16 | isothermal 55C |
| D5 | 20 | isothermal 55C |
| E1 | 5 | isothermal 60C |
| E2 | 8 | isothermal 60C |
| E3 | 12.5 | isothermal 60C |
| E4 | 16 | isothermal 60C |
| E5 | 20 | isothermal 60C |

How to run each strategy on the rig (hardware/firmware):
- `ramp ...`  -> `python hardware/firmware/host_ramp.py --design design.json --port <COM>`
  (edit `--t-hot/--t-cold/--anneal-min` when you recompile, or step a sous-vide bath).
- `isothermal T` -> hold the block at T (firmware `SET <T>`) for 1-4 h, then cool.

Gel-score every well together (run cold, 1x TAE + ~11 mM MgCl2, 60-90 V). The
condition with the sharpest monomer band wins.

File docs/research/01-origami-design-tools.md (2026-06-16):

# 01 — DNA Origami Fundamentals + Automated Shape→Scaffold-Routing Software

Research dossier for **Molecular Synth v0** — a desktop open-hardware rig that uses DNA self-assembly
(DNA origami) to manufacture atomically-precise nanostructures, plus a software compiler
(**shape → DNA staple recipe**).

> **Scope honesty up front.** DNA origami reliably makes **~10 nm to ~1 µm** structures (single particles;
> with hierarchical assembly, lattices/gigadalton objects). It does **NOT** make macroscopic objects, and it
> does **NOT** do Drexler-style diamondoid mechanosynthesis — that remains **simulation/theory only**, never
> experimentally demonstrated (see "North-star" section). Everything marked `demonstrated=true` below is an
> actual wet-lab result in the cited paper.

---

## 1. The scientific backbone (all peer-reviewed, all web-verified)

### 1.1 Rothemund 2006 — scaffolded DNA origami (the founding paper)
- **Citation:** Paul W. K. Rothemund, "Folding DNA to create nanoscale shapes and patterns," *Nature* **440**, 297–302 (2006). DOI: 10.1038/nature04586. <https://www.nature.com/articles/nature04586>
- **What it demonstrated (lab):** Folded a single ~7 kb single-stranded scaffold (M13) into arbitrary **2D** shapes
  (squares, stars, smiley faces, a map) by raster-filling the shape and adding ~200+ short "staple" oligos.
  Imaged by AFM. This is the canonical method the whole field is built on.
- **Key design numbers introduced:** scaffold raster-filled into rows of parallel helices; staples are ~32 nt
  (binding 2–3 scaffold segments); crossovers placed at periodic intervals; helices ~6 nm apart.

### 1.2 Douglas et al. 2009 — 3D origami + caDNAno
- **Citation:** Shawn M. Douglas, Hendrik Dietz, Tim Liedl, Björn Högberg, Franziska Graf, William M. Shih,
  "Self-assembly of DNA into nanoscale three-dimensional shapes," *Nature* **459**, 414–418 (2009).
  DOI: 10.1038/nature08016. <https://www.nature.com/articles/nature08016> (PMC: PMC2688462)
- **Companion software paper:** Douglas, Marblestone, Teerapittayanon, Vazquez, Church, Shih, "Rapid prototyping
  of three-dimensional DNA-origami shapes with caDNAno," *Nucleic Acids Research* **37**, 5001–5006 (2009).
  DOI: 10.1093/nar/gkp436. caDNAno: <https://cadnano.org/>
- **What it demonstrated (lab):** Extended origami to **3D** by stacking helices on a **honeycomb lattice**;
  built monolith, square nut, railed bridge, slotted/stacked cross, etc. **caDNAno** is the GUI CAD tool that
  made manual 3D design tractable — still the field-standard editor.

### 1.3 Ke et al. 2012 — DNA bricks (scaffold-free, modular "voxels")
- **Citation:** Yonggang Ke, Luvena L. Ong, William M. Shih, Peng Yin, "Three-Dimensional Structures
  Self-Assembled from DNA Bricks," *Science* **338**, 1177–1183 (2012). DOI: 10.1126/science.1227268.
  <https://www.science.org/doi/10.1126/science.1227268> (PubMed 23197527)
- **What it demonstrated (lab):** A **scaffold-free** alternative: 32-nt "bricks," each binding 4 neighbors
  like interlocking LEGO. From a master "molecular canvas" they removed/added bricks to sculpt **100+ distinct
  3D shapes** in a single annealing pot. Important because it's the "voxel compiler" mental model — a 3D shape
  is just a subset of bricks toggled on/off.

### 1.4 Benson et al. 2015 — polygonal mesh → DNA (vHelix)
- **Citation:** Erik Benson, Abdulmelik Mohammed, Johan Gardell, Sergej Masich, Eugen Czeizler, Pekka Orponen,
  Björn Högberg, "DNA rendering of polyhedral meshes at the nanoscale," *Nature* **523**, 441–444 (2015).
  DOI: 10.1038/nature14586. <https://www.nature.com/articles/nature14586>
- **Tool:** **vHelix**, an Autodesk Maya plug-in. <http://www.vhelix.org/>
- **What it demonstrated (lab):** Took **arbitrary closed polygonal meshes** and rendered them as
  wireframe DNA (ball, bottle, bunny, etc.). First time an artist's 3D mesh could be folded with minimal
  manual routing. Uses a relaxation/optimization to assign helices to mesh edges.

### 1.5 Veneziano et al. 2016 — DAEDALUS (fully automatic top-down routing) ★ core of the compiler
- **Citation:** Rémi Veneziano, Sakul Ratanalert, Kaiming Zhang, Fei Zhang, Hao Yan, Wah Chiu, Mark Bathe,
  "Designer nanoscale DNA assemblies programmed from the top down," *Science* **352**, 1534 (2016).
  DOI: 10.1126/science.aaf4388. <https://www.science.org/doi/10.1126/science.aaf4388> (PubMed 27229143)
- **Tool / code:** **DAEDALUS**; Python re-implementation **pyDAEDALUS** at <https://github.com/lcbb/pyDAEDALUS>.
- **What it demonstrated (lab):** **Fully automatic inverse design** — input is just a geometric mesh
  (PLY), output is the complete scaffold route + all staple sequences, with **no manual editing**. Built and
  characterized 45 wireframe objects (tetrahedron→icosahedron, cuboctahedron, nested cube, etc.) by cryo-EM/AFM.
  This is the algorithmic heart of a "shape→recipe" compiler.

### 1.6 Jun et al. 2019 — PERDIX / TALOS / (and METIS) automated wireframe suites
- **PERDIX (free-form 2D):** Hyungmin Jun, Fei Zhang, Tyson Shepherd, Sakul Ratanalert, Xiaodong Qi, Hao Yan,
  Mark Bathe, "Autonomously designed free-form 2D DNA origami," *Science Advances* **5**, eaav0655 (2019).
  DOI: 10.1126/sciadv.aav0655. <https://www.science.org/doi/10.1126/sciadv.aav0655>
  PERDIX = *Programmed Eulerian Routing for DNA Design using X-overs.*
- **TALOS (3D polyhedral, honeycomb edges):** Hyungmin Jun, Tyson R. Shepherd, Kaiming Zhang, William P.
  Bricker, Shanshan Li, Wah Chiu, Mark Bathe, "Automated Sequence Design of 3D Polyhedral Wireframe DNA Origami
  with Honeycomb Edges," *ACS Nano* **13**, 2083–2093 (2019). DOI: 10.1021/acsnano.8b08671. (PubMed 30605605)
- **METIS (2D, stiffer 6-helix-bundle / honeycomb edges):** Hyungmin Jun, Xiao Wang, William P. Bricker,
  Mark Bathe, "Automated sequence design of 2D wireframe DNA origami with honeycomb edges," *Nature
  Communications* **10**, 5419 (2019). DOI: 10.1038/s41467-019-13457-y.
  <https://www.nature.com/articles/s41467-019-13457-y>
- **ATHENA (unifying GUI + later rapid-prototyping):** Jun, Wang, Bricker, Jackson, Bathe, "Rapid prototyping
  of arbitrary 2D and 3D wireframe DNA origami," *Nucleic Acids Research* **49**, 10265–10274 (2021).
  DOI: 10.1093/nar/gkab762. GUI: <https://github.com/lcbb/athena>. METIS source: <https://github.com/hmjeon/METIS-pub>.
- **What they demonstrate (lab):** The Bathe-lab line that turns DAEDALUS into a usable toolchain — input a CAD
  geometry (PLY / SVG / IGES), get scaffold+staple sequences for DX-edge (PERDIX), 6HB-edge (METIS), or 3D
  honeycomb-edge (TALOS) wireframes, all validated by AFM/cryo-EM in the papers.

---

## 2. Design/simulation software stack (what the compiler actually wraps)

| Tool | Role | Open-source? | Install | Input → Output formats |
|---|---|---|---|---|
| **caDNAno** | Manual 2D/3D origami CAD (lattice editor) | Yes (BSD) | desktop / Autodesk Maya plug-in; `pip`-era forks exist | `.json` (caDNAno) |
| **scadnano** | Browser + scriptable port of caDNAno | Yes (MIT) | web app + `pip install scadnano` | `.sc` (scadnano JSON), exports caDNAno `.json`, oxDNA, oxView, IDT plate CSV |
| **vHelix** | Mesh→DNA (Maya plug-in) | Yes | Maya plug-in | `.ply` mesh → routed design |
| **pyDAEDALUS** | Top-down mesh→scaffold+staples | Yes | Python (clone repo) | `.ply` → caDNAno `.json` + staple sequence list |
| **PERDIX/TALOS/METIS/ATHENA** | Automated wireframe sequence design | Yes | Fortran/Python + GUI | `.ply`/`.svg`/`.iges` → scaffold+staple CSV, caDNAno `.json`, oxDNA |
| **oxDNA / oxpy** | Coarse-grained MD/MC validation of the design | Yes (GPL) | `git clone` + CMake `-DPython=1` → `oxpy`; optional CUDA GPU | `.top` + `.dat`/`.conf` (oxDNA topology+config) |
| **oxView** | Browser visualizer/editor of nanostructures | Yes | web (`sulcgroup/oxdna-viewer`) | reads oxDNA `.top/.dat`, `.oxview`; imports caDNAno via tacoxDNA |
| **tacoxDNA** | Format converter hub | Yes | web (tacoxdna.sissa.it) + Python | caDNAno/PDB/LAMMPS/cadnano↔oxDNA |
| **NUPACK** | Nucleic-acid thermodynamics / sequence design | Yes (academic) | `pip` (NUPACK 4) | sequences → MFE structure, pair probs, melt |
| **ViennaRNA** | Secondary-structure / folding energetics | Yes | `pip install ViennaRNA` / conda | sequence → structure/energy |

### 2.1 scadnano (Doty et al.)
- **Citation:** David Doty, Benjamin L. Lee, Tristan Stérin, "scadnano: A Browser-Based, Scriptable Tool for
  Designing DNA Nanostructures," *DNA 26* (LIPIcs vol. 174), 9:1–9:17 (2020). DOI: 10.4230/LIPIcs.DNA.2020.9.
  arXiv: 2005.11841. Web app: <https://scadnano.org/>. Python lib:
  <https://github.com/UC-Davis-molecular-computing/scadnano-python-package> (`pip install scadnano`).
- **Why it matters for the compiler:** It's the most automation-friendly editor — pure-Python scripting
  generates designs programmatically and exports directly to **IDT plate order files** and oxDNA. This is the
  natural "back end" for a shape→recipe compiler that needs to emit an orderable oligo plate.

### 2.2 oxDNA coarse-grained model (Ouldridge / Snodin / Šulc / Romano / Doye / Louis / Rovigatti)
- **Original model:** Thomas E. Ouldridge, Ard A. Louis, Jonathan P. K. Doye, "Structural, mechanical, and
  thermodynamic properties of a coarse-grained DNA model," *J. Chem. Phys.* **134**, 085101 (2011).
  DOI: 10.1063/1.3552946. arXiv: 1009.4480.
- **Sequence-dependent (oxDNA2):** P. Šulc, F. Romano, T. E. Ouldridge, L. Rovigatti, J. P. K. Doye, A. A.
  Louis, "Sequence-dependent thermodynamics of a coarse-grained DNA model," *J. Chem. Phys.* **137**, 135101
  (2012). DOI: 10.1063/1.4747335.
- **Modern code/JOSS:** Poppleton, Matthies, et al., "oxDNA: coarse-grained simulations of nucleic acids made
  simple," *JOSS* (2023). Code + docs: <https://github.com/lorenzo-rovigatti/oxDNA>,
  <https://lorenzo-rovigatti.github.io/oxDNA/>.
- **What it does:** Coarse-grained MD that predicts whether a designed origami will actually fold/be stable
  (it is **simulation**, not a wet-lab demonstration — used to validate designs before ordering oligos).

### 2.3 oxView (Poppleton et al.) + oxDNA.org webserver
- **Citation:** Erik Poppleton, Joakim Bohlin, Michael Matthies, Shuchi Sharma, Fei Zhang, Petr Šulc, "Design,
  optimization and analysis of large DNA and RNA nanostructures through interactive visualization, editing and
  molecular simulation," *Nucleic Acids Research* **48**, e72 (2020). DOI: 10.1093/nar/gkaa417.
- **Protocols paper:** Bohlin, Matthies, Poppleton, et al., "Design and simulation of DNA, RNA and hybrid
  protein–nucleic acid nanostructures with oxView," *Nature Protocols* **17**, 1762–1788 (2022).
  DOI: 10.1038/s41596-022-00688-5.
- **oxDNA.org server:** Poppleton et al., *Nucleic Acids Research* **49**, W491 (2021). DOI: 10.1093/nar/gkab324.
  <https://oxdna.org/> — run oxDNA in the browser with no install.

### 2.4 NUPACK (Zadeh et al.) and ViennaRNA
- **NUPACK:** J. N. Zadeh, C. D. Steenberg, J. S. Bois, B. R. Wolfe, M. B. Pierce, A. R. Khan, R. M. Dirks,
  N. A. Pierce, "NUPACK: Analysis and design of nucleic acid systems," *J. Comput. Chem.* **32**, 170–173
  (2011). DOI: 10.1002/jcc.21596. (Companion design paper: Zadeh, Wolfe, Pierce, *JCC* **32**, 439, 2011,
  DOI 10.1002/jcc.21633.) NUPACK 4 is `pip`-installable.
- **Use in compiler:** sequence-level QC — check staples don't form strong hairpins/dimers, estimate melting,
  optionally redesign sequences to hit a target ensemble defect.

---

## 3. The top-down mesh→scaffold-routing ALGORITHM (the compiler core)

This is the piece the software compiler must implement. Distilled from DAEDALUS (Veneziano 2016) and
PERDIX/TALOS (Jun 2019):

1. **Input:** a closed surface as a polygonal mesh (`.ply`) — vertices `V`, edges `E`, faces `F`.
2. **Edge → duplex assignment:** each mesh edge becomes one (DX, 2-duplex) or more (6HB) parallel DNA
   duplexes. Edge length is quantized to an integer number of helical turns; **B-DNA ≈ 10.5 bp/turn**, so an
   edge of *n* turns ≈ `round(10.5 × n)` bp (DAEDALUS uses multiples of ~10.5 to keep crossovers in phase).
3. **Scaffold routing = spanning tree:** A single scaffold strand must traverse the whole object exactly once.
   DAEDALUS builds a **spanning tree of the mesh** (Prim's algorithm). The spanning-tree edges get a
   **scaffold double-crossover**; non-tree edges are bridged so the scaffold makes **one continuous closed
   route** — equivalent to finding an **Eulerian circuit** of the (doubled) edge graph. Doubling every edge
   guarantees all vertices have even degree ⇒ an Eulerian circuit always exists.
4. **A-trail (for some wireframe schemes):** an **A-trail** is an Eulerian circuit that always turns to the
   "next" edge around each vertex (a non-crossing/face-respecting Eulerian circuit). A-trails let the scaffold
   route a wireframe with a **single scaffold and no scaffold crossovers between layers**, simplifying folding
   (used by vHelix-style and square-lattice wireframe routing; ref: Mohammed/Czeizler/Orponen on Eulerian
   circuits with turning costs; "Computer-Aided Design of A-Trail Routed Wireframe DNA Nanostructures with
   Square Lattice Edges," PMC10100577).
5. **Staple generation:** staples are laid antiparallel to the scaffold, ~**32 nt** typical, each crossing
   between adjacent duplexes at **crossover points**. Crossover spacing in lattice origami is periodic:
   honeycomb lattice ~7 bp (≈0.66 turn) between crossovers; square lattice ~8 bp; edges/seams placed so a
   crossover lands every ~half-to-three-quarter turn. Staples are broken to be ~18–50 nt and to have adequate
   binding domains (≥~8 nt per domain) for thermal stability.
6. **Sequence assignment:** the scaffold sequence (M13, see §4) is threaded along the route; each staple's
   sequence is the Watson–Crick complement of the scaffold segments it covers. Optional NUPACK/ViennaRNA pass
   flags problematic staples.
7. **Output:** caDNAno/scadnano `.json` for inspection, oxDNA `.top/.dat` for simulation, and a **staple list
   (sequence + well position) as a plate CSV** ready to order.

---

## 4. The M13mp18 scaffold (the "feedstock" the compiler threads)

- **What it is:** the circular single-stranded genome of bacteriophage **M13mp18**, **7,249 nucleotides**, the
  canonical origami scaffold (Rothemund 2006 onward). Variants exist at 7,308 / 7,560 / 7,704 / 8,064 / 8,634 nt.
- **Where the sequence is canonically obtained:** GenBank accession for M13mp18 RF is **X02513** (M13mp18 is
  the M13 cloning vector lineage); the 7,249-nt ssDNA scaffold sequence is distributed with caDNAno/scadnano
  as a built-in scaffold string and is also published in the Rothemund 2006 supplement. (Vendor: NEB N4040;
  Tilibit/now part of community suppliers historically distributed p7249.)
- **Orderable as a consumable:** **NEB N4040 "M13mp18 Single-stranded DNA," 10 µg (~$52, VWR/Fisher/NEB).**
  10 µg ≈ ~4 nmol of a 7249-nt strand — enough for many small folding reactions.

---

## 5. Buildable rig — Molecular Synth v0 (hobbyist, USA, < $1500 rig target)

**Honest framing of the wet process:** DNA origami folding is shockingly low-tech to *run* (the design is the
hard part). A folding reaction = mix scaffold + staples in Mg²⁺ buffer (TAE-Mg / "folding buffer"), then run a
**thermal anneal ramp** (heat to ~90–95 °C, cool slowly to ~20 °C over 1–16 h). Readout/QC = **agarose gel
electrophoresis** (does it migrate as a folded band?) and, for actual shape confirmation, **AFM or TEM** — AFM
is the only nm-resolution imager remotely in hobby reach, and even a used one usually blows the budget, so v0
treats imaging as "send-out / collaborator" and proves folding by gel mobility.

The two rig essentials a hobbyist must own: **(a) a programmable thermal ramp** and **(b) gel
electrophoresis**. Both are repurposable/affordable:

- **Thermal ramp (the only truly custom build):** a **Peltier (TEC) + aluminum block + Arduino PID** controller
  is the standard DIY thermocycler — exactly the OpenPCR / "coffee-cup PCR" pattern. For origami you don't even
  need fast cycling, just a smooth slow cool, which a sous-vide-grade TEC controller does well.
- **Gel + power supply:** a sub-$200 all-in-one education gel kit covers QC.
- **All-in-one fallback:** **Bento Lab** ($1,999) bundles thermocycler+centrifuge+gel+transilluminator but is
  *over* the $1,500 rig budget; listed as optional.

See `parts` in the structured payload for orderable URLs/prices. Consumables (scaffold, staples, buffer,
stain) are counted separately from the rig budget.

---

## 6. North-star vs. demonstrated (ruthless honesty)

- **Demonstrated today:** programmable self-assembly of **single nanostructures 10 nm–1 µm**, wireframe
  polyhedra, 3D lattices, nm-precise placement of dyes/proteins/nanoparticles on an origami "breadboard."
  Higher-order: gigadalton assemblies and crystalline lattices via hierarchical origami (Wagenbauer et al.,
  *Nature* 2017; Tikhomirov et al., *Nature* 2017 — fractal/µm-scale arrays). Still **nano-to-micro**, not
  macroscopic.
- **NOT demonstrated (north-star / simulation only):** Drexler-style **diamondoid mechanosynthesis** — building
  stiff covalent solids atom-by-atom with positionally-controlled tooltips. This exists only in **theory/DFT/MD**
  (e.g., tooltip-reaction DFT studies), **never an experimental lab demonstration**. Any "atomically-precise
  manufacturing of hard materials" claim for Molecular Synth must be labeled `demonstrated=false`.
- **Therefore the compiler's honest promise:** "shape (mesh) → orderable DNA staple recipe that self-assembles
  a ~10 nm–1 µm scaffolded nanostructure," validated in silico by oxDNA and in vitro by gel. Not a matter
  compiler.

---

## 7. Code facts the software compiler needs (cheat-sheet)

- **Pip/conda installable:** `scadnano` (pip), `oxpy`/oxDNA (CMake build, optional CUDA), `ViennaRNA` (pip/conda),
  NUPACK 4 (pip, academic license). pyDAEDALUS / METIS / ATHENA = clone-from-GitHub (Python/Fortran).
- **File formats:** caDNAno `.json`; scadnano `.sc` (JSON); oxDNA `.top` (topology) + `.dat`/`.conf`
  (configuration); `.oxview` (richer JSON w/ colors, strand names, base pairs); mesh input `.ply`
  (also SVG/IGES for ATHENA/METIS); structural `.pdb`; IDT plate order = CSV (name, sequence, well, scale).
- **Conversions:** tacoxDNA (caDNAno/PDB/LAMMPS ↔ oxDNA); scadnano exports caDNAno+oxDNA+oxView+IDT CSV.
- **Routing algorithm:** mesh → spanning tree (Prim) → double edges → Eulerian circuit (A-trail variant for
  non-crossing wireframe) → scaffold route → antiparallel staples at periodic crossovers.
- **Magic numbers:** B-DNA **10.5 bp/turn**; staples **~32 nt** (18–50 nt range, ≥~8 nt per binding domain);
  crossover spacing honeycomb **~7 bp**, square lattice **~8 bp**; inter-helix spacing ~2.5–2.6 nm (lattice).
- **Scaffold:** **M13mp18, 7,249 nt** (GenBank X02513 lineage; built into caDNAno/scadnano as p7249).
- **Validation pass:** oxDNA MD (CPU or CUDA GPU) for fold stability; NUPACK/ViennaRNA for staple hairpin/dimer
  and melt QC.

---

## Sources (key URLs)
- Rothemund 2006: <https://www.nature.com/articles/nature04586>
- Douglas 2009 (3D): <https://www.nature.com/articles/nature08016> · caDNAno: <https://cadnano.org/>
- Ke 2012 (bricks): <https://www.science.org/doi/10.1126/science.1227268>
- Benson 2015 (vHelix): <https://www.nature.com/articles/nature14586> · <http://www.vhelix.org/>
- Veneziano 2016 (DAEDALUS): <https://www.science.org/doi/10.1126/science.aaf4388> · <https://github.com/lcbb/pyDAEDALUS>
- Jun 2019 PERDIX: <https://www.science.org/doi/10.1126/sciadv.aav0655> · TALOS: 10.1021/acsnano.8b08671 · METIS: <https://www.nature.com/articles/s41467-019-13457-y> · ATHENA: <https://github.com/lcbb/athena>
- scadnano: <https://scadnano.org/> · <https://github.com/UC-Davis-molecular-computing/scadnano-python-package>
- oxDNA: <https://github.com/lorenzo-rovigatti/oxDNA> · <https://lorenzo-rovigatti.github.io/oxDNA/> · oxView: <https://github.com/sulcgroup/oxdna-viewer> · oxDNA.org: <https://oxdna.org/>
- NUPACK: <https://onlinelibrary.wiley.com/doi/10.1002/jcc.21596>
- M13mp18 scaffold (consumable): NEB N4040 <https://www.neb.com/products/n4040-m13mp18-single-stranded-dna>
- miniPCR: <https://www.minipcr.com/product/minipcr-mini8x-thermal-cycler/> · Bento Lab: <https://bento.bio/product/bento-lab-rs/>
- IVYX gel system: <https://www.amazon.com/Electrophoresis-System-Power-Supply-Timer/dp/B0B2ZSRG2Z>

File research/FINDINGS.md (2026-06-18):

# Research findings — molecular-level study of the compiler

Measured, reproducible experiments probing the physics/chemistry at the heart of the
DNA-origami compiler, and one scale-physics study sparked by a design question. Every
number below is produced by a script in this folder; re-run to verify.

```bash
python research/exp1_tm_salt_calibration.py     # Tm validation + folding-buffer salt calibration
python research/exp2_scale_physics.py           # "what if we built molecules but bigger?" — the physics of scale
python research/exp3_design_sweet_spots.py      # scaffold-offset lever + objective ablation
python research/exp4_gc_uniformity_offset.py    # ingenuity lever: GC-uniformity-guided offset selection
python research/exp5_why_scale_matters.py       # WHY size matters at bedrock, and the dodge
python research/exp6_physics_redteam.py          # adversarial physics/materials audit of the end product
python research/exp9_kinetic_ladder.py            # kinetic folding-ORDER term (optional, default OFF): Tm-ladder
python research/exp10_hierarchy.py               # hierarchy: origami unit cells -> super-lattice (compose the scales)
```

Deps: Biopython (independent NN thermodynamics) for exp1; pure stdlib for exp2/exp3.

---

## Exp 1 — the Tm model is correct, but mis-calibrated for its own buffer

**Validation.** molsynth's nearest-neighbor Tm (`compiler/molsynth/sequences.py`, SantaLucia
1998) matches Biopython's independent `DNA_NN3` table to **mean |ΔT| = 0.86 °C** (max 3.3 °C)
over 400 random 32–42 nt staples, with matched 62.5 nM strand concentration and the same
Owczarzy-2004 monovalent salt correction. **The implementation is sound.**

**Calibration gap (the finding).** The compiler defaults to `na_M = 0.05` (50 mM Na⁺), but
origami folds in **12.5 mM MgCl₂**. Mg²⁺ stabilises duplexes far more than its naive monovalent
equivalent. Against the physically-correct Owczarzy-2008 divalent model (Biopython `saltcorr=7`,
`Mg=12.5`):

| [Na⁺] used in molsynth | mean Tm gap vs Mg²⁺ ground truth |
|---|---|
| 13 mM (docstring's `120·√[Mg]` rule) | **−21.9 °C** (badly wrong) |
| 50 mM (current default) | **−8.9 °C** (too low) |
| ~166 mM (buffer-accurate equivalent) | ≈ 0 °C |

So the default under-predicts folding-buffer Tm by **~9 °C**, and the docstring's rule-of-thumb
is ~22 °C low. **Recommendation:** set the diagnostics/protocol Tm to `na_M ≈ 0.166` (or add a
proper `mg_mM` path using the Owczarzy-2008 correction). A uniform offset does **not** change the
optimiser's *relative* cut-placement search (variance term is offset-invariant), but it does fix
the absolute Tm window penalty and the numbers a wet-lab user reads. This couples to Exp 3(B).

Refs: SantaLucia 1998 (PNAS 95:1460); Owczarzy 2004 (Biochem 43:3537); Owczarzy 2008 (Biochem 47:5336).

---

## Exp 2 — "what if we built molecules, but bigger?" (the physics of scale)

A creative prompt: the universe feels recursively self-similar, so could we reconstruct a
molecule at a graspable size and make, e.g., giant food? The honest physics has **two true
halves**:

1. **Structure** *can* be self-similar across scale — fractals, critical phenomena, turbulent
   cascades, the renormalization group. The "patterns repeat up/down" intuition is real.
2. **Forces are not scale-invariant.** The dimensionless ratios (surface/volume,
   gravity/thermal, binding/thermal) change with linear size *L*, so a **different force
   dominates at each scale**. You cannot "scale a molecule up": a bond is ~0.15 nm of quantum
   orbital overlap — stretch it and it stops being a bond. Properties (taste, color, stiffness,
   melting) are *emergent at their scale*.

Computed crossovers (300 K, ρ≈1100 kg/m³, σ_bind≈20 mJ/m²):

- **Gravity = thermal at L ≈ 0.79 µm.** Below: the Brownian/colloidal world — objects shuffle
  themselves and *self-assemble*. Above: gravity wins — it just falls and sits, you need hands.
- **Self-transport by thermal motion:** a 50 nm origami diffuses **4.2 µm/s** (≈80× its body
  length) — it finds its own binding partners. An apple "diffuses" **4 nm/s** — frozen.
- **Binding beats thermal noise** for any interface ≳ 0.5 nm; by ~10 nm assemblies are robustly
  multi-*kT* and hold a programmed shape.

**The manipulation/self-assembly sweet spot is ~10 nm – 0.8 µm** — small enough that thermal
motion builds it for free by the trillions, large enough to hold a designed shape and be
addressed/imaged. **That is exactly the DNA-origami window this repo compiles.** The honest path
molecule→macroscopic is **hierarchical self-assembly** (glucose → cellulose → cell wall →
lettuce — which nature already runs for food), not inflating one molecule. Our buildable lever is
to *program the bottom rung* (origami) and let hierarchy carry it up. See `docs/north-star.md`
for why macroscopic atom-up replication stays north-star.

---

## Exp 3 — where the compiler's design levers actually pay off

**(A) Scaffold-offset is a big free lever.** M13mp18 is circular, so the route's start position
is free. Over 24 offsets (octahedron), the yield proxy ranges **best 73 → worst 205** (spread
132; the worst start is ~3× worse). The compiler's 8-sample search lands within **6.4** of the
global optimum — so the search is genuinely worth it, and there is modest headroom for a smarter
search (more samples, or GC-uniformity-guided — see below).

**(B) Which molecular terms do real work** (octahedron; Δ = how much worse the design gets under
the full objective when a term is removed):

| term removed | Δ full-score | reading |
|---|---|---|
| Tm-window | **+8.85** | dominant — absolute Tm targeting matters most |
| internal-repeat | +5.21 | M13 k-mer repeats are real |
| hairpin | +4.87 | self-structure matters |
| Tm-variance | +1.91 | modest (and delicate — see prior session) |
| loop-entropy | −1.3 | ~slack for a small shape (matters on large presets) |
| off-target | −1.0 | ~slack here (few long repeats span a short edge) |

**Key molecular insight:** the staple **Tm spread stays ~6.4 °C across every ablation** — it is
floored by M13's *intrinsic local GC heterogeneity*, not by where you cut. Cooperative annealing
(the high-yield lever, Aksel 2024) is therefore limited by the scaffold sequence itself.

**Coupling to Exp 1 (a concrete, testable improvement).** Octahedron staples already average
**66 °C** at the (under-calibrated) 50 mM — *above* the optimiser's `tm_hi = 64`. The
buffer-correct +9 °C pushes the real mean to ~75 °C, far above the window, so the optimiser is
fighting a mis-calibrated target. The coherent fix is to **recalibrate `na_M` and shift the Tm
window together** (≈ [59, 73] °C) so the dominant objective term targets real folding-buffer
temperatures.

---

## Exp 4 — the ingenuity sweet spot, confirmed: pick the offset for GC-uniformity

Exp 3 said the Tm-spread floor is set by M13's GC landscape and the offset is free. **Tested and
confirmed:** across 16 octahedron offsets, the windowed-GC standard deviation of the routed
region correlates with the staple Tm spread the optimiser actually achieves at

**Pearson r = +0.73.**

Achieved Tm-sd ranges **2.94 → 6.47 °C** across offsets — so selecting the most GC-uniform start
could roughly **halve** the cooperative-annealing Tm spread versus the worst, a direct
high-yield lever (Aksel 2024). The compiler currently ranks offsets by the general yield proxy,
which captures this only indirectly. **Concrete improvement:** add a GC-uniformity term to the
offset ranking in `compile_shape()`'s scaffold search — cheap (no extra anneal) and targets the
one floor that cut-placement cannot move. This is the highest-leverage, lowest-risk next step,
and it stacks with the Exp 1 buffer recalibration.

---

## Exp 5 — WHY size matters at bedrock, and the dodge

The root cause is **geometry of exponents, not a wall**. Every force is sourced by a
different-dimensional feature of an object, so each scales as a different power of linear size L
(measured slopes, log-log):

| quantity | exponent n (E ∝ Lⁿ) | sourced by |
|---|---|---|
| thermal kT | **0** (constant!) | one degree of freedom — scale-free |
| surface (vdW, adhesion, drag, tension) | **2** | interfaces (area) |
| gravity / weight | **3–4** | amount of stuff (volume) |
| diffusive reach per second | **−0.5** | thermal vs viscous drag |

A "crossover scale" is simply where two lines of different slope intersect (gravity = thermal at
~0.79 µm). **The bedrock that cannot be dodged:** the atomic scale is pinned by the fundamental
constants — the Bohr radius `a₀ = 4πε₀ℏ²/(mₑe²) = 0.053 nm` derives from raw constants in the
script. Bonds (~0.15 nm), bond energy (~eV), and kT (~0.026 eV) are all set there. There is no
"bigger atom," and kT is scale-free — so as you move away from the atomic scale, the *count* of
fundamental units (atoms, bonds, area, volume) changes and each force, caring about a different
count, re-sorts. That is the entire origin of why size matters.

**Why you can't "have it all ways" in one object — and the dodge.** A *monolithic* object has
one size, so the L³-vs-L²-vs-L⁰ competition already picked a winner; it can't be both
thermally-self-assembling (needs small) and rigidly gravity-defying (needs big). But a
**multi-scale** object can. Nature never accepts the 1/L surface penalty: it makes area fractal,
A ∝ L^D with D→3. A solid 15 cm sphere has 0.07 m² of surface; a 15 cm human lung packs **~75 m²
(>1000× more)** by nesting airways across scales — molecular-scale surface chemistry *and*
macroscopic size simultaneously. Bone, wood, nacre, gut, mitochondria all do this. **You don't
break the scaling laws; you compose them across scales** (paying structural complexity + energy).
That — not inflating a molecule — is "the missing something," and it's exactly the lever DNA
origami opens at the bottom rung (program the smallest scale; let hierarchy carry it up). Two
further escapes the passive laws don't see: **active matter** (burn energy to fight the scaling,
as living cells do) and **metamaterials** (engineered structure gives bulk properties the base
chemistry "shouldn't" have).

---

## Exp 6 — physics & materials red-team (audit the end product like code)

Thinking like a security auditor, but the "exploits" are physical assumptions that break the
*real folded object* even when `compile_shape()` succeeds and every file is written. Findings
(audited over the 11 committed designs):

| # | severity | finding | evidence | the lever (not a wall) |
|---|---|---|---|---|
| F1 | HIGH | single-duplex wireframe edges are thermally **floppy** | every edge ~63 bp → RMS bend **~38°** (WLC, Lp≈50 nm); 11/11 designs | stiffness is a *design variable*: multi-helix-bundle edges (6HB Lp ~1–10 µm, ~20–70× stiffer) → large rigid shapes. **Now reported in diagnostics.** |
| F2 | HIGH | Tm mis-calibrated for the Mg²⁺ buffer | Exp 1: real staples ~**+9 °C** hotter than the 50 mM default | `sequences.tm_buffer()` added; diagnostics report the offset. Next: shift the optimiser window +9 °C. |
| F3 | MED | G-quadruplex sequestration not screened | audited **490 staples → 0 G4 motifs** (clean today) | `g_quadruplex_sites()` added + reported; promote to an optimiser term before novel/denser sequences. |
| F4 | MED | objective is thermodynamic; folding is **kinetic** | no topological-order term (optimizer.py); pathway control matters (Dunn 2015; Sobczak 2012) | program a Tm ladder matched to assembly order (seams last) → kinetic programming toward ~100% yield. |

**What shipped from this audit (additive, no orderable output changed):** a *Physics & materials
reality check* section in every `diagnostics.md` (edge-stiffness verdict, G4 audit,
buffer-accurate Tm offset, kinetic caveat), backed by three new validated functions in
`sequences.py` (`tm_buffer`, `g_quadruplex_sites`, `wlc_rms_bend_deg`) and 4 new tests. The
digital pipeline was already sound; these are the physics gaps that decide whether the *atoms*
cooperate — and none of them is a wall. Each is a design lever toward making the impossible
buildable.

---

## Exp 10 — hierarchy: compose the scales (the next rung toward macroscopic)

Exp 2/5 said the honest molecule→macro path is *hierarchical self-assembly*, not inflating one
molecule. Exp 10 makes that ladder quantitative for **this repo's output**: take a cube origami
unit cell (~40 nm), let it tile a 3D lattice via sticky-end handles (4 units/edge per level), and
recurse. At each level we compute the two physics crossovers that decide whether the rung
self-builds — **gravity vs thermal** (exp2's `(kT/ρg)^¼` form, identical constants) and **handle
binding vs thermal**.

**The measured self-assembly ladder** (300 K, ρ=1100 kg/m³, 4 handles/interface, 8-bp sticky ends):

| level | units | size | gravity/kT | diffuse/s | bind/kT | regime |
|---|---|---|---|---|---|---|
| 0 | 1 | 40 nm | 6.7e-6 | 4.7 µm/s | 47 | self-assembles |
| 1 | 64 | 160 nm | 1.7e-3 | 2.3 µm/s | 47 | self-assembles |
| 2 | 4,096 | 640 nm | 0.44 | 1.2 µm/s | 47 | self-assembles |
| 3 | 262,144 | 2.6 µm | 1.1e+2 | 586 nm/s | 47 | **too heavy → falls/sits** |
| 4 | 1.7e7 | 10 µm | 2.9e+4 | 293 nm/s | 47 | too heavy |
| 5 | 1.1e9 | 41 µm | 7.3e+6 | 146 nm/s | 47 | too heavy |
| 6 | 6.9e10 | 164 µm | 1.9e+9 | 73 nm/s | 47 | too heavy |

**Finding 1 — self-assembly has a hard ceiling, and it is exactly exp2's.** The gravity = thermal
crossover lands at **L ≈ 0.79 µm** (787 nm) — the same number exp2/exp5 derive, because it is the
same `(kT/ρg)^¼` with the same constants. So free Brownian super-assembly carries you up to about
**level 2 (640 nm, ~4,000 units)**; at **level 3 (2.6 µm)** gravity already beats thermal by ~100×
and the trillion-fold Brownian search that built the bottom rung dies. That is not a wall — it is
the **measured hand-off point** where you must switch mechanism (silica/metal hardening = rung 1 of
the-ladder.md, templated placement, or active/energy-burning assembly).

**Finding 2 — super-assembly stability is monotonic in handle valence (the bottom-rung design
lever).** Per-handle binding free energy is **~1.7 kT for a 4-bp toehold, ~11.7 kT for an 8-bp
sticky end** (NN free energy ~1.5 kcal/mol·bp, net of the ~+5 kcal/mol nucleation/entropy penalty).
Total interface binding is strictly increasing in handle count for both lengths (verified 1→12
handles): a weak 4-bp handle needs ~2 handles to clear the ~3-kT "stays together" bar and ~5 to be
robust, while an 8-bp handle is robustly multi-kT almost alone. **Valence + handle length is the
programmable knob** that decides whether the lattice holds, and it sits squarely in the window this
compiler already targets.

**The honest read:** origami (~40 nm) is right in the exp2 sweet spot; a couple of levels of
handle-driven tiling reach ~0.6 µm blocks that *still* self-assemble — then gravity takes over. You
don't inflate the molecule, you **compose scales and switch mechanism at the measured 0.79 µm
crossover**. Self-contained, no compiler-core change; self-checks assert the crossover matches
exp2's ~0.79 µm and that binding-vs-kT is monotonic in handle count.

## Exp 9 — a kinetic Tm-ladder term (addresses F4): program folding ORDER, not just the endpoint

Exp 6/F4 flagged that the objective is **thermodynamic** (equilibrium Tm clustering) and ignores
folding **ORDER** — yet folding is kinetic: as the pot cools, staples bind in descending-Tm
order, so the hottest engage first. If a loop-/seam-closing staple is also among the hottest it
can close before its framework nucleates → a kinetic trap (Sobczak et al., Science 338:1458, 2012;
Dunn et al., Nature 525:82, 2015).

**What shipped (OPTIONAL, default OFF — existing behaviour byte-identical):** a `w_kinetic` term
(`optimizer.kinetic_penalty`, default weight **0.0**). A staple's *load* = (# crossovers it
bridges) + `kinetic_loop_w`·ln(largest enclosed loop); the term penalises the positive covariance
between load and Tm, rewarding a gradient where high-load (seam) staples are NOT the hottest. A
default model (`w_kinetic=0`) scores **exactly** (`==`) a pre-term model, so no committed output
changes.

**Measured (cube, seed 12345, 3000 iters; `research/exp9_kinetic_ladder.py`):**

| metric | term OFF (default) | term ON (w_kinetic=8) |
|---|---|---|
| Pearson r(crossover-count, Tm) | +0.043 | **+0.012** |
| Pearson r(crossover+loop load, Tm) | +0.071 | **+0.029** |
| kinetic covariance (penalty) | 0.186 | **0.075** (−60%) |
| mean Tm: crossover − non-crossover staples | +0.53 °C | **+0.15 °C** |

So enabling the term measurably drives crossover-heavy staples toward the COOL end (framework
nucleates first). A deterministic unit check confirms the penalty correctly ranks a *framework-first*
ladder (cost 0) below a *seam-first* one (cost 1.67).

**Honest structural finding (why the lever is modest on the presets):** the existing length window
(staples ≤ 42 nt) is *shorter* than the ~63 bp inter-crossover spacing of these single-duplex
wireframes, so **a staple physically cannot bridge two crossovers — max crossover-load is 1 for
every preset.** The term's lever here is the binary crossover-vs-framework Tm ordering and the
enclosed-loop size; it bites hardest on **denser / multi-helix-bundle designs** (the F1 stiffness
fix) where staples do carry >1 crossover. This is a **kinetic PROXY** built from the equilibrium
Tm ranking — there is **no MD kinetic simulator** — and it stays a design lever toward the
~100%-yield kinetic programming that F4 points at.

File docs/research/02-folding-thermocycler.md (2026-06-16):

# 02 — The Folding Reaction + Repurposed Thermocycler Hardware

**Domain:** Molecular Synth v0 — the thermal annealing step that drives scaffolded DNA origami
self-assembly, and the cheapest honest hardware that can run it.

**One-line truth:** DNA origami folding is a *single-pot anneal*: mix one long "scaffold" strand +
~200 short "staple" strands in a Mg²⁺ buffer, heat to denature, then cool slowly. The "machine" is
nothing more than a programmable temperature box. A real qPCR thermocycler is **not required** — a
PID-controlled heat block, a sous-vide circulator, or even an isothermal hold can fold many designs.
This is the most de-risked subsystem of the whole rig.

---

## 1. The canonical folding protocol (web-verified)

### 1.1 Rothemund 2006 — the founding paper

Paul W. K. Rothemund, *"Folding DNA to create nanoscale shapes and patterns,"* **Nature 440,
297–302 (2006)**, DOI: 10.1038/nature04586.
<https://www.nature.com/articles/nature04586>

- Mechanism: a ~7-kilobase single-stranded **scaffold** (M13mp18 phage genome, ~7249 nt) is
  "raster-filled" through the target 2D shape; ~200+ short synthetic **staple strands**
  (each ~32 nt) cross-link the scaffold back on itself at crossovers.
- Self-assembly is **a single step**: mix, heat, cool. Staples pull the scaffold into shape as the
  solution cools.
- Result: ~100 nm structures (squares, disks, triangles, a 5-pointed star, a smiley face) at ~6 nm
  spatial resolution. **This bounds the whole product: origami makes ~10 nm–1 µm objects, not
  macroscopic ones.**
- Rothemund's original anneal: heat to ~90–95 °C, cool to ~20 °C at ~1 °C/min over ~2 hours, in
  TAE buffer + ~12.5 mM MgCl₂, staples in large excess over scaffold.

### 1.2 Castro et al. 2011 — the practical primer (THE protocol reference)

Castro C. E., Kilchherr F., Kim D.-N., Shiao E. L., Wauer T., Wortmann P., Bathe M., Dietz H.,
*"A primer to scaffolded DNA origami,"* **Nature Methods 8, 221–229 (2011)**,
DOI: 10.1038/nmeth.1570. <https://www.nature.com/articles/nmeth.1570>

- The step-by-step community standard for designing (caDNAno), folding, purifying, and imaging
  origami. Introduces CanDo for predicting 3D solution shape + flexibility.
- Folding mix: scaffold + staples in **1× TAE buffer with added MgCl₂** (commonly 12.5–20 mM Mg²⁺
  depending on 2D vs 3D), staples at **~5–10× molar excess** per scaffold.
- Thermal annealing ramp from denaturation (~65–80 °C) down to RT; complex 3D objects often need a
  long, slow ramp (hours to days) and a **per-design MgCl₂ + temperature screen**.

### 1.3 Wagenbauer et al. 2017 — modern "How We Make DNA Origami"

Wagenbauer K. F., Engelhardt F. A. S., Stahl E., Hechtl V. K., Stömmer P., Seebacher F.,
Meregalli L., Ketterer P., Gerling T., Dietz H., *"How We Make DNA Origami,"*
**ChemBioChem 18(19), 1873–1885 (2017)**, DOI: 10.1002/cbic.201700377.
<https://chemistry-europe.onlinelibrary.wiley.com/doi/abs/10.1002/cbic.201700377>

- The current bench-reality protocol from the Dietz lab. Confirms folding is dominated by two
  knobs you screen empirically: **MgCl₂ concentration** and **thermal ramp**.
- Standard reaction: ~20 nM scaffold + ~100–200 nM each staple (so ~5–10× per staple) in TAE-Mg²⁺.

### 1.4 Consensus reaction recipe (what the compiler should emit)

| Parameter | Value | Source |
|---|---|---|
| Scaffold | M13mp18-derived ssDNA (p7249 / p7560 / p8064), 10–20 nM | Rothemund 2006; Wagenbauer 2017 |
| Staples | ~5–10× molar excess per staple (e.g. 100 nM each at 20 nM scaffold) | Castro 2011; Wagenbauer 2017 |
| Buffer | 1× TAE (40 mM Tris-acetate, 1 mM EDTA) | Castro 2011 |
| MgCl₂ | **12.5 mM** default (2D); 16–20 mM for dense 3D; 5–10 mM for wireframe | Castro 2011; Wagenbauer 2017 |
| Denature | 90–95 °C hold ~5 min (2D) or 65–80 °C (gentle 3D) | Rothemund 2006; Castro 2011 |
| Anneal | slow cool to 20–25 °C | all |
| Total time | ~2 h (simple 2D) to 12–60 h (complex 3D) | Rothemund 2006; Castro 2011 |

---

## 2. Do you actually need a thermocycler? (No — strong evidence)

This is the budget-critical question. Three independent literature results say a precise programmable
ramp is sufficient and that **isothermal folding is even possible**, so a $35 PID heat block or a
sous-vide circulator replaces a $3k–10k qPCR machine.

### 2.1 Slow linear/controlled cool is the workhorse

- Rothemund's own 2D shapes folded on a simple cool from ~90 °C → 20 °C at ~1 °C/min (~2 h). A
  heat block or water bath with a slow controlled ramp reproduces this.
- Community protocols (e.g. the open iNANO/Dresden origami protocol) use ramps like 65 °C → 25 °C
  over hours, or nonlinear 16 h ramps — all of which a microcontroller-driven heater can execute.
  <https://inanobotdresden.github.io/origami-protocol.html>

### 2.2 Isothermal folding — no ramp at all (Dietz lab)

Sobczak J.-P. J., Martin T. G., Gerling T., Dietz H., *"Rapid folding of DNA into nanoscale shapes
at constant temperature,"* **Science 338, 1458–1461 (2012)**, DOI: 10.1126/science.1229919.
<https://www.science.org/doi/10.1126/science.1229919>

- Demonstrated that many origami objects fold to high yield by simply **holding at a single
  constant temperature** (each design has an optimal folding temperature, often ~45–60 °C), some
  in **minutes**. This means a fixed-setpoint heater/water bath can fold real structures — no ramp
  hardware needed for those designs.

### 2.3 Isothermal with denaturant / in cell media (even gentler hardware)

- Jiang, Z. et al. (representative) and follow-on work show isothermal assembly using denaturing
  agents (formamide) at lower temperatures, and ultra-fast isothermal formation of DNA
  nanostructures in culture media — further loosening the temperature-control requirement.
  *Isothermal Assembly of DNA Origami Structures Using Denaturing Agents*, **J. Am. Chem. Soc.**
  <https://pubs.acs.org/doi/10.1021/ja8030196>

**Honest scope caveat:** isothermal/slow-cool works *well for robust designs* (2D sheets, simple
bundles). **Dense 3D origami** (Dietz-style honeycomb/square-lattice solids) still folds best with a
multi-hour optimized ramp and a per-design MgCl₂ × temperature screen — exactly what a *programmable*
PID box (not just a fixed bath) buys you. So: build the programmable PID heat block, and you get both
the easy isothermal cases and the harder ramp cases.

---

## 3. The repurposed hardware (orderable today, USA, no lab account)

Design: a small **aluminum heat block** holding 0.2 mL PCR tubes, sandwiched on a **Peltier (TEC)**
for active heat *and* cool, the TEC's hot side bonded to a **CPU heatsink+fan**, driven by a
**power MOSFET** from a **12 V PSU**, with a **PID controller / Arduino + thermistor** closing the
loop. This is just a 3D-printer-hotend / PC-cooling / sous-vide stack rebadged as a thermocycler.

### Path A — fastest, dumbest, cheapest: sous-vide immersion circulator
A consumer sous-vide circulator already *is* a ±0.1 °C closed-loop water bath. Float PCR tubes in
the bath, set the isothermal folding temp (Sobczak 2012) or step it manually for a coarse ramp.
~$50–80, zero electronics. Best first validation.

### Path B — programmable ramp box (the real rig): PID + Peltier
| Part | Role | Repurposed from | Vendor | ~Price |
|---|---|---|---|---|
| TEC1-12706 Peltier (40×40 mm, 12 V, 60 W) | active heat + cool element under the block | CPU/cooler/dehumidifier TEC | Amazon (SMAKN/DAOKI etc.) | $8–13 |
| Inkbird ITC-100VH PID + SSR + K-probe kit | closed-loop temperature control (no-code path) | brewing/sous-vide/kiln controller | Amazon / inkbird.com | $35 |
| Arduino Uno R3 (programmable-ramp path) | runs the ramp schedule, PWM the MOSFET, read thermistor | hobby microcontroller | store.arduino.cc | $27 (Uno R3 SMD) / ~$10 clones |
| IRLB8721 logic-level N-MOSFET | Arduino-driven power switch for the TEC | 3D-printer/Arduino power switching | Amazon (BOJACK 10-pk) | ~$8 / 10 |
| 100K NTC 3950 thermistor (3D-printer hotend type) | temperature feedback into Arduino | 3D-printer hotbed/hotend sensor | Amazon (Cylewet/Gikfun 10-pk) | ~$8 / 10 |
| 96-well aluminum PCR cooling block (0.2 mL) | holds tubes, even thermal mass on the TEC | lab/PCR cooling block (consumer-sold) | Amazon | ~$15 |
| 12 V 30 A 360 W switching PSU (w/ fan) | powers TEC + electronics | LED-strip / 3D-printer PSU | Amazon (EAGWELL/ALITOVE) | ~$25 |
| CPU heatsink + 12 V fan (≥40 mm) | dumps TEC hot-side heat | PC CPU cooler | Amazon | ~$10 |

**Rig hardware subtotal (Path B): ~$135–150.** Well under the $1500 ceiling — leaves headroom for a
USB microscope/imaging subsystem and an electrophoresis verification rig (covered in other docs).
Consumables (scaffold, staple oligo pool, TAE, MgCl₂, PCR tubes) are counted separately.

### Why a TEC, not just a resistive heater
Folding needs both a fast **heat** to 90 °C and a **controlled cool**. A bare resistive cartridge
can only heat; cooling then relies on ambient loss (slow, uncontrolled). A Peltier reverses polarity
to actively pump heat out, giving a *controlled* downward ramp — the variable that matters most for
yield. (For Path A, the circulator's pump + ambient handles cooling.)

---

## 4. code_facts — exact numbers the compiler must emit

The software compiler ("shape → staple recipe") should output a folding protocol block with these
defaults, overridable per design class:

- **Buffer:** `1x TAE` (40 mM Tris-acetate, 1 mM EDTA, pH ~8.3) `+ 12.5 mM MgCl2` (default 2D).
  - 3D dense lattice: bump MgCl₂ to `16-20 mM`. Wireframe: drop to `5-10 mM`.
- **Concentrations:** scaffold `20 nM`; each staple `100 nM` → **5× per staple** (use `200 nM` for
  10×). Equivalently emit "staple:scaffold = 5–10×".
- **Default slow-ramp schedule (2D, ~2 h):**
  - hold `95 °C` for `5 min` (denature)
  - linear cool `95 °C → 20 °C` at **`1 °C / min`** (≈75 min)
  - hold `20 °C` (store at 4 °C)
- **Standard 3D ramp (Dietz-style, overnight):**
  - hold `65 °C` for `15 min`
  - ramp `60 °C → 40 °C` at **`−1 °C / hour`** (the design-critical window), then fast cool to 20 °C
  - total ~20–60 h depending on object
- **Isothermal option (Sobczak 2012):** single hold at the design's optimal fold temp, typically in
  the `45–60 °C` band, for `minutes to hours`; emit as `ISOTHERMAL T=<screened>°C`.
- **MgCl₂ × temperature screen grid** the compiler should suggest when yield is unknown:
  MgCl₂ ∈ {5, 8, 12.5, 16, 20} mM × fold-temp/ramp-window ∈ {coarse ramp, hold 50, 55, 60 °C}.
- **Scaffold identity:** M13mp18-derived, length matched to design (`p7249`, `p7560`, or `p8064`).
- **Staple length:** ~`32 nt` typical (caDNAno crossover spacing); pool = "one tube per staple" or
  premixed equimolar pool.
- **Anneal volume:** 0.2 mL PCR tubes, ~50 µL reaction; ramp executed in the aluminum block on the
  TEC (PID setpoint stream) or in the sous-vide bath.
- **PID/Arduino control facts:** 100K NTC 3950 thermistor + matching pull-up (typ. 4.7 kΩ) on an
  ADC pin; Steinhart-Hart or β=3950 conversion; PWM the IRLB8721 gate to modulate TEC power;
  the ramp program is just a setpoint-vs-time table the firmware interpolates.

---

## 5. Honest scope / what this subsystem does NOT do

- It controls **temperature only**. It does not synthesize DNA, image the product, or verify yield —
  those are separate subsystems (oligo ordering is a consumable; AFM/gel/USB-scope is verification).
- Folding makes **~10 nm–1 µm** addressable nanostructures. It is **not** Drexler/diamondoid
  mechanosynthesis — that remains **simulation/theory only, demonstrated=false, north-star**. DNA
  origami is the real, demonstrated path to atomically-*defined* (sequence-addressed) nanoscale
  assembly, not atomically-precise covalent diamond machining.
- Yield is design-dependent. The hardware gives you the knobs (Mg²⁺, ramp); achieving high yield on
  a *new* shape still requires the empirical screen described above.

---

## Sources
- Rothemund 2006, Nature — <https://www.nature.com/articles/nature04586>
- Castro et al. 2011, Nature Methods — <https://www.nature.com/articles/nmeth.1570>
- Wagenbauer et al. 2017, ChemBioChem — <https://chemistry-europe.onlinelibrary.wiley.com/doi/abs/10.1002/cbic.201700377>
- Sobczak et al. 2012, Science — <https://www.science.org/doi/10.1126/science.1229919>
- Isothermal w/ denaturant, JACS — <https://pubs.acs.org/doi/10.1021/ja8030196>
- Open origami protocol (Dresden) — <https://inanobotdresden.github.io/origami-protocol.html>
- Parts: TEC1-12706 <https://www.amazon.com/SMAKNTM-TEC1-12706-Thermoelectric-Cooler-Peltier/dp/B00J3F7YKC> ·
  Inkbird ITC-100VH <https://www.amazon.com/Inkbird-Thermostat-Temperature-Controller-ITC-100VH/dp/B00T2IODEK> ·
  Arduino Uno R3 <https://store.arduino.cc/products/arduino-uno-rev3> ·
  IRLB8721 <https://www.amazon.com/BOJACK-IRLB8721-Transistors-IRLB8721PBF-N-Channel/dp/B083WMH7CD> ·
  NTC 3950 <https://www.amazon.com/Cylewet-Thermistor-Temperture-Printer-CYT1064/dp/B06XR1TG5N> ·
  Al PCR block <https://www.amazon.com/Aluminum-Cooling-Block-%EF%BC%8C96-Well-96-Well/dp/B09MJHY27W> ·
  12V 30A PSU <https://www.amazon.com/EAGWELL-Universal-Regulated-Switching-Computer/dp/B06XW76584>

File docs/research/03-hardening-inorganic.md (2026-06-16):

# 03 — Hardening the Soft DNA Template into a HARD Inorganic Structure

**Project:** Molecular Synth v0 — desktop DNA-origami nanofab rig
**This module:** turning the floppy, water-soluble DNA-origami "master pattern" into a rigid, robust inorganic replica (silica, metal oxide, or solid metal).
**Date:** 2026-06-16
**Scope honesty up front:** Everything here makes structures in the **~10 nm – 1 µm** range. Nothing here makes a macroscopic object. Drexler-style diamondoid mechanosynthesis is NOT in this document and is NOT demonstrated — it is north-star/simulation-only. What IS demonstrated and reproducible is *templated inorganic transcription* of a DNA shape into a hard material.

---

## Why harden at all?

A bare DNA-origami object is:
- only stable in **high-Mg²⁺ / high-salt** buffer (falls apart in low salt, pure water, or biological fluid),
- mechanically floppy (persistence length of dsDNA ~50 nm; origami is a soft hydrogel-like solid),
- degraded by nucleases and by drying (collapses under capillary forces / TEM vacuum without stabilization).

Hardening converts the DNA from "the product" into "the **template/mold**." After hardening you can dry it, image it in vacuum SEM/TEM, etch with it, or use it as a real material. This is the single most important step that turns a DNA-origami hobby into a *nanomanufacturing* rig.

There are three demonstrated routes, in increasing equipment cost:

1. **Sol–gel silicification** (DNA → SiO₂ shell) — **DIY-feasible in a tube.** ← primary route for this build
2. **Metal casting in DNA molds** (DNA cavity → solid Au/Ag) — DIY-feasible chemistry, harder QC
3. **Atomic layer deposition (ALD)** (DNA → conformal TiO₂/ZnO/Al₂O₃) — **NOT a home build**; needs a vacuum ALD reactor. Mark optional / fab-service-only.

---

## ROUTE 1 — Sol–gel silicification (PRIMARY, DIY-feasible)
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

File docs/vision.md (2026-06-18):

# vision.md — the molecular synthesizer (and what's real *today*)

You want the Orville/Star-Trek synthesizer: describe a thing — and it appears, built with
atomic precision. That is the right north star. This file is the honest map of it, held to
the project rule: **we only keep pushing on the parts that are possible in today's world
with today's cheap materials.**

## The honest truth, in one line

A **universal matter replicator** — arbitrary macroscopic, *functional* objects
materialised from atoms on demand — is **not possible today, at any price.** It needs
positional covalent mechanosynthesis (atom-by-atom assembly of bulk solids), which has
**never been demonstrated** (DFT/simulation only — see [`north-star.md`](north-star.md)).
Anyone who tells you otherwise is selling something.
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

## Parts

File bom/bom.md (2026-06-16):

# Bill of Materials — Molecular Synth v0

_Auto-generated from [`bom.json`](bom.json) by `render_bom.py` (the same file the
[validation gate](../validate/validate.py) checks). Prices are snapshot estimates
(USA, 2026-06); treat as ±20% and verify at order time._

## Totals
- **Rig hardware: $623**  (target < $1500 — PASS)
- **Core consumables (per design): $570**  (staple oPool path; addressable plate adds ~$550)
- Optional tracks (STM, silica hardening, sous-vide) are listed separately and not in the rig total.

## Rig hardware (durable, the < $1500 rig)
| Part | Role | Repurposed from | Vendor | Price | Link |
|---|---|---|---|---|---|
| TEC1-12706 Peltier module (40x40 mm, 12 V, 60 W) | active heat AND cool element under the aluminium folding block | CPU cooler / dehumidifier thermoelectric module | Amazon (SMAKN) | $11 | [link](https://www.amazon.com/SMAKNTM-TEC1-12706-Thermoelectric-Cooler-Peltier/dp/B00J3F7YKC) |
| BTS7960 IBT-2 H-bridge driver | bidirectional Peltier drive (PWM heat + reverse-polarity cool) for thermocycler.ino | smart-car / robot DC-motor driver module | Amazon (HiLetgo) | $12 | [link](https://www.amazon.com/HiLetgo-BTS7960-Driver-Arduino-Current/dp/B00WSN98DC) |
| Arduino Uno R3 | runs the anneal ramp, PID loop, drives the H-bridge, reads thermistor | hobby microcontroller | Arduino | $27 | [link](https://store.arduino.cc/products/arduino-uno-rev3) |
| 100K NTC 3950 thermistor (10-pack) | temperature feedback for the PID loop | 3D-printer hot-end / hot-bed sensor | Amazon (Cylewet) | $8 | [link](https://www.amazon.com/Cylewet-Thermistor-Temperture-Printer-CYT1064/dp/B06XR1TG5N) |
| 96-well aluminium PCR cooling block (0.2 mL) | even thermal mass holding the folding tubes on the Peltier | PCR/lab cooling block (consumer-sold) | Amazon | $15 | [link](https://www.amazon.com/Aluminum-Cooling-Block-%EF%BC%8C96-Well-96-Well/dp/B09MJHY27W) |
| 12 V 30 A 360 W switching PSU | powers the Peltier + electronics | LED-strip / 3D-printer power supply | Amazon (EAGWELL) | $25 | [link](https://www.amazon.com/EAGWELL-Universal-Regulated-Switching-Computer/dp/B06XW76584) |
| CPU heatsink + 12 V fan | dumps the Peltier hot-side heat | PC CPU cooler | Amazon | $10 | [link](https://www.amazon.com/s?k=cpu+heatsink+12v+fan) |
| IVYX Scientific Mini Gel Electrophoresis System (tank + integrated 35/50/100 V supply + combs) | fold-QC gel; the integrated 50/100 V supply meets the 60-90 V origami requirement | education-grade all-in-one gel rig | Amazon (IVYX) | $160 | [link](https://www.amazon.com/Electrophoresis-System-Power-Supply-Timer/dp/B0B2ZSRG2Z) |
| Blue-LED transilluminator (470 nm) | visualize GelGreen/GelRed-stained bands (eye/skin-safe, no UV) | blue-light gel imager | Amazon | $130 | [link](https://www.amazon.com/Light-Transilluminator-470nm-Electrophoresis-Visualization/dp/B0B2ZDFM8D) |
| Mini vortex mixer | mix folding + silicification reactions | nail-polish / paint / tattoo-ink vortex (same device) | Amazon (INTLLAB) | $35 | [link](https://www.amazon.com/INTLLAB-Function-Adhesives-Vortexer-Stainless/dp/B0CWL3TP83) |
| Mini benchtop centrifuge (7000 rpm) | spin-downs + PEG-precipitation purification of folded origami | lab/hobby microcentrifuge | Amazon (CryoKing) | $100 | [link](https://www.amazon.com/CryoKing-Centrifuges-Centrifuge-Microcentrifuge-Laboratory/dp/B0DHXHKGK7) |
| Adjustable micropipette set (2-20, 20-200, 100-1000 uL) + tips | dispense uL volumes for all wet steps | lab micropipettes (sold direct to consumers) | Amazon | $90 | [link](https://www.amazon.com/s?k=adjustable+micropipette+set+2-1000ul) |

## Consumables (per design / reusable starter kit)
| Part | Role | Repurposed from | Vendor | Price | Link |
|---|---|---|---|---|---|
| M13mp18 single-stranded scaffold DNA (NEB N4040, 10 ug) | the scaffold strand the compiler threads (p7249, 7249 nt) | purpose-made consumable (sequencing/cloning template) | NEB | $40 | [link](https://www.neb.com/products/n4040-m13mp18-single-stranded-dna) |
| Staple oligos as IDT oPool (~200 sequences, one tube) | the staple set; cheapest route for a first proof-of-fold | purpose-made consumable | IDT | $200 | [link](https://www.idtdna.com/pages/products/custom-dna-rna/dna-oligos/custom-dna-oligos/opools-oligo-pools) |
| MgCl2 hexahydrate, ACS, 500 g | folding cation (12.5 mM Mg2+) + gel running buffer (~11 mM) | ACS reagent (consumer-sold) | Amazon (GFS) | $35 | [link](https://www.amazon.com/GFS-Chemicals-48801-Magnesium-Hexahydrate/dp/B01NBML9XZ) |
| 50x TAE buffer concentrate, 1 L | folding + gel buffer (dilute to 1x) | purpose-made consumable | Amazon | $25 | [link](https://www.amazon.com/50X-TAE-Buffer-Tris-Acetate-EDTA-1L/dp/B09V5MVMN9) |
| Agarose, molecular-biology grade, 100 g | gel matrix (~2% for origami QC) | purpose-made consumable | Amazon | $45 | [link](https://www.amazon.com/Agarose-Molecular-Biology-Grade-P05-SR01-100/dp/B00S9ZJFLI) |
| GelGreen nucleic-acid stain, 10000x, 0.5 mL | DNA-safe band stain (EtBr replacement; blue-light optimized) | purpose-made consumable | Amazon (Biotium) | $110 | [link](https://www.amazon.com/GelGreen-Nucleic-Acid-Stain-Water/dp/B07RY6BJMT) |
| DNA ladder (100 bp - 1 kb) | size marker lane on the gel | purpose-made consumable | Amazon (IVYX) | $40 | [link](https://www.amazon.com/IVYX-Scientific-Ladders-Electrophoresis-100bp/dp/B0GPMJCW2Q) |
| PEG-8000, 500 g | PEG-precipitation purification of folded origami (Stahl 2014) | consumer-sold reagent | Amazon | $40 | [link](https://www.amazon.com/s?k=peg+8000+500g) |
| 0.2 mL PCR 8-tube strips (~125) | folding-reaction vessels | purpose-made consumable | Amazon | $15 | [link](https://www.amazon.com/PCR-Tubes-0-2ml-Strip-Included/dp/B09CVDBMQ9) |
| Nuclease-free water, 1 L | all dilutions / buffers | purpose-made consumable | Amazon | $20 | [link](https://www.amazon.com/Quality-Biological-351-029-131-Molecular-Endotoxin/dp/B07T14KWBZ) |

## Optional (alternative + stretch-track parts)
| Part | Role | Repurposed from | Vendor | Price | Link |
|---|---|---|---|---|---|
| Sous-vide immersion circulator (alternative folding bath) | isothermal / manual-step folding (Sobczak 2012); zero-electronics Path A | kitchen sous-vide cooker | Amazon | $60 | [link](https://www.amazon.com/s?k=sous+vide+immersion+circulator) |
| 3D-printed gel box + thermocycler collar + STM mount (PLA/PETG filament) | the parametric hardware/cad/*.scad parts | 3D printer filament | Amazon | $15 | [link](https://www.amazon.com/s?k=petg+filament+1kg) |
| Piezo buzzer disc 27 mm (15-pack) [STM] | cut into quadrants -> XYZ scanner (Berard/Open-STM) | doorbell / alarm piezo buzzer | Amazon | $9 | [link](https://www.amazon.com/15-Pieces-Elements-Electrode-Oscillator/dp/B00DH2UKYO) |
| Teensy 4.0 [STM] | real-time STM scan/feedback controller | hobby microcontroller | Adafruit | $25 | [link](https://www.adafruit.com/product/4323) |
| LF356 JFET op-amp [STM] | transimpedance amp: pA-nA tunnelling current -> voltage | general-purpose op-amp | Mouser | $2 | [link](https://www.mouser.com/c/?series=LF356) |
| TEOS (tetraethyl orthosilicate), 500 mL [hardening] | silica source for sol-gel hardening (Liu 2018) | consumer-sold reagent | LabPro | $42 | [link](https://labproinc.com/products/tetraethyl-orthosilicate-500ml-t0100-500ml) |
| APTES or TMAPS aminosilane (nucleator) [hardening] | cationic/amine nucleation layer on DNA before silica condensation | consumer/lab reagent | Sigma-Aldrich | $178 | [link](https://www.sigmaaldrich.com/US/en/product/aldrich/741442) |
| Pt/Ir wire 90:10, 0.25 mm, 30 cm [STM] | hand-cut STM tip (~50 tips per length) | consumer-sold precious-metal wire | Surepure Chemetals | $60 | [link](https://www.surepure.com/Platinum-Iridium-Wire-Rod-90-Percent-Platinum-10-Percent-Iridium/a/1432,1,815) |
| HOPG sample (grade B, 5x5x1 mm) [STM] | conductive test specimen whose atomic lattice the STM resolves | consumer-sold graphite sample | Amazon | $90 | [link](https://www.amazon.com/Oriented-Pyrolytic-Graphite-Priority-Shipping/dp/B08D94B6JW) |

---
_Honesty notes: search-URL lines (CPU cooler, filament, PEG, pipette set, sous-vide)
point at a live orderable category rather than one SKU — pick any reputable listing.
The compiler emits both an oPool order (`staples_opool.txt`, ~$200) and an addressable
plate order (`staples_idt_plate.txt`, ~$750); choose your cost point._

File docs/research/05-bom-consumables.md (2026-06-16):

# BOM 05 — Consumables & Sourcing Reality Check (Wet-Lab Biochemistry Inputs)

**Project:** Molecular Synth v0 — desktop DNA-origami rig + shape→staple compiler
**Scope of this doc:** The *consumable* (use-up) chemistry inputs for ONE DNA-origami design (~200 staple strands, M13mp18 scaffold). Hardware (thermocycler/heat-block, gel rig, centrifuge, imaging) is costed separately in the rig BOM. This doc answers: *can a hobbyist with a credit card and no institutional account actually buy these, and what does one design honestly cost?*
**Date verified:** 2026-06-16. Prices are list/snapshot and drift; treat ±20%.

---

## 0. The honest headline

- **A single ~200-staple DNA-origami design costs roughly $700–$1,000 in consumables if you buy staples as individual tubes in a 96-well plate at IDT** (the staples dominate). The scaffold, buffers, gel, and stain together are only ~$150–$250 and most of that is reusable across dozens of designs.
- **If you buy the 200 staples as a single IDT oPool (pooled synthesis) instead of individual tubes, the staple cost collapses to ~$100–$400**, but you lose the ability to address individual strands (no selective omission, no per-staple handles) and concentrations are lower/less precise. For a first proof-of-structure (e.g. Rothemund smiley / a rectangle), an oPool is the cheapest viable route. For anything with functionalized handles or selective-staple experiments, you need the addressable plate.
- **Yes, a US hobbyist can buy from IDT and NEB with a personal credit card and no institutional account.** Both accept Visa/MC/Amex and ship to residential addresses. This is verified below. The DNA itself (M13 scaffold, short oligos) is **not** controlled/regulated — these are standard molecular-biology reagents. (The one place to be careful: vendors screen *gene-length* synthetic DNA against pathogen sequences; origami staples are 20–60 nt and far below any concern.)
- **Nothing in the consumable list strictly requires an institution.** The only items that are "lab-account-flavored" (Amicon filters, some MgCl2 grades) all have Amazon-purchasable equivalents listed below.

---

## 1. Scaffold ssDNA (M13mp18 / p7249) — the "blank canvas"

The scaffold is the single long circular ssDNA (~7,249 nt for M13mp18) that the staples fold. Two real, hobbyist-buyable sources:

### 1a. NEB N4040 — M13mp18 Single-stranded DNA
- **Vendor:** New England Biolabs (neb.com) and resellers (Fisher).
- **Product:** N4040S, M13mp18 ssDNA, **10 µg @ 1 µg/µL**.
- **Price:** **~$40** (N4040S, per NEB 2024 price list). [NEB product page](https://www.neb.com/products/n4040-m13mp18-single-stranded-dna) · [NEB 2024 pricing PDF](https://www.umassmed.edu/globalassets/enzyme-freezer/documents/neb-2024-pricing.pdf) · [Fisher listing](https://www.fishersci.com/shop/products/m13mp18-single-stranded-dna/50811790)
- **Reality:** NEB sells to individuals with a credit card; ships in the US to residential addresses. 10 µg = ~4.2 pmol at 7249 nt (MW ≈ 2.39 MDa). A "standard" origami fold uses ~10 nM scaffold in 50–100 µL = ~0.5–1 pmol per reaction, so **10 µg ≈ 4–8 folding reactions.** Cheap entry, but you will burn through it fast if you iterate. *Caveat: NEB's M13mp18 is sold as a sequencing/cloning template; it is the same sequence cadnano calls "M13mp18," so it works as a scaffold, but it is not concentration-optimized for origami the way tilibit's is.*

### 1b. tilibit nanosystems — Scaffold ssDNA p7249 (origami-grade)
- **Vendor:** tilibit nanosystems (tilibit.com), the spin-out that productized DNA-origami reagents.
- **Product:** p7249 ssDNA (sequence identical to cadnano "M13mp18"). Options:
  - 0.5 mL @ 100 nM = 50 pmol (112 µg), **~25 folding reactions** — **€112 (~$120)**
  - 2 mL @ 100 nM = 200 pmol (448 µg), ~100 reactions — same €112/unit tier scales down to €0.5/µg
  - 2 mL @ 400 nM = 800 pmol (1792 µg), ~400 reactions — €0.35/µg
- **Price/URL:** **€112 (~$120)** base. [tilibit p7249 product](https://www.tilibit.com/products/single-stranded-scaffold-dna-type-p7249) · [tilibit scaffold collection](https://www.tilibit.com/collections/scaffold-dna)
- **Reality:** tilibit ships internationally and is the de-facto origami scaffold vendor; it is delivered pre-quantified at origami concentration ("sufficient for ~25 standard reactions"). For a hobbyist this is the *less error-prone* choice (you don't have to QC your own scaffold), at ~3× the per-reaction cost of NEB. Ships from Germany — expect customs/shipping and a longer lead time to the US.

**Recommendation for v0:** Start with **NEB N4040 ($40)** to validate the rig cheaply; switch to tilibit if scaffold-quality is suspected as the failure mode. GuildBio also resells M13 scaffolds but tilibit/NEB are the two reliably-stocked routes.

---

## 2. Staple oligos — the dominant cost, and the one real decision

A ~200-staple design = ~200 distinct short oligos (typically 32–42 nt; ~7,000–8,400 total bases across the set).

### 2a. Option A — IDT individual oligos in a 96-well plate (addressable, the standard origami route)
- **Vendor:** Integrated DNA Technologies (idtdna.com). Order as **"Plates"** (HotPlates / standard plate). Minimum 48 oligos/plate; ~200 staples = ~3 plates of 96 wells (~2 full + 1 partial).
- **Format:** 25 nmol scale, **desalted (standard)** — the correct, cheapest purification for origami staples (no HPLC/PAGE needed; origami tolerates n-1 truncation products).
- **Price reality:** IDT does **not** publish a flat per-base number on a stable public URL (the FAQ pages redirect/paywall), but the well-established community figure for **25 nmol desalted plate oligos is ≈ $0.06–$0.10 per base**, plus a per-plate setup/normalization handling fee. Working the math:
  - ~200 staples × ~38 nt avg = ~7,600 bases × ~$0.09/base ≈ **$680** in synthesis
  - + plate handling (~3 plates) ≈ **$50–$150**
  - **≈ $700–$850 total for the addressable staple set.**
- **URLs:** [IDT plate ordering](https://www.idtdna.com/site/Order/menu/Sub?type=plate) · [IDT DNA-origami reagents](https://www.idtdna.com/pages/products/custom-dna-rna/dna-oligos/custom-dna-oligos/dna-origami-reagents) · [HotPlates](https://www.idtdna.com/pages/products/custom-dna-rna/dna-oligos/custom-dna-oligos/hotplates-oligos)
- **Why this format:** Each well = one addressable strand. You can omit specific staples (to leave docking sites), add 3′/5′ handles to chosen strands, or do selective experiments. This is what every origami lab uses.

### 2b. Option B — IDT oPools (pooled synthesis, cheapest per base, NOT individually addressable)
- **Vendor:** IDT oPools. One tube containing all ~200 sequences mixed.
- **Price reality:** oPools is priced as **a flat plate/pool fee (~$103–$109) plus a per-base rate that is dramatically lower than tube synthesis** for hundreds of sequences. For ~200 short staples (~7,600 bases, well under the first 3,300-base tier breakpoint into higher tiers) the **all-in cost is typically ~$100–$400** depending on length tier — i.e. **roughly 2–7× cheaper than the addressable plate.** [IDT oPools](https://www.idtdna.com/pages/products/custom-dna-rna/dna-oligos/custom-dna-oligos/opools-oligo-pools) · [oPools launch / spec (synbiobeta)](https://www.synbiobeta.com/read/idt-launches-opools-tm-oligo-pools-the-longest-highest-fidelity-and-ready-to-use-custom-oligo-pools-on-the-market)
- **The catch (be honest):** You get **one tube of everything**. You cannot leave out a staple, cannot put a handle on just one strand, and the per-strand concentration is low and only approximately equimolar. It is excellent for "does my rig fold a known shape at all?" with a published staple set, and useless for selective/functionalized work. Yield per pool is also limited (you can't fold dozens of reactions from one pool the way you can from 25 nmol tubes).

### 2c. Option C — Twist Bioscience oligo pools
- **Vendor:** Twist (twistbioscience.com). Twist's oligo pools are even cheaper per base at large N, but **Twist's account onboarding is more institution-oriented** and minimum-order/lead-time friction is higher for an individual. For a hobbyist, IDT (tube *or* oPool) is the path of least resistance. Listed here for completeness, not recommended for v0.

### Staple decision summary

| Route | ~200-staple cost | Addressable? | Best for |
|---|---|---|---|
| IDT plate, 25 nmol desalted | **~$700–$850** | Yes (per well) | Real origami, handles, selective staples |
| IDT oPools | **~$100–$400** | No (one tube) | First proof-of-fold of a known shape |
| Twist pools | lowest at scale | No | Not v0-friendly (account/MOQ friction) |

**v0 recommendation:** First fold of a *published* shape → **oPool (~$200)**. Once the rig is proven and you want your own/functionalized designs → **IDT 25 nmol desalted plate (~$750)**.

---

## 3. Buffers, gel, stain, plasticware, purification (all reusable across many designs)

These are bought once and amortize across dozens of designs. All are Amazon-buyable by a hobbyist; lab-account substitutes are noted.

### 3a. MgCl₂ (folding cation — origami folds in ~12–20 mM Mg²⁺)
- **GFS Chemicals 48801, Magnesium Chloride Hexahydrate, ACS reagent, 500 g** — Amazon, **~$30–$45**. [Amazon B01NBML9XZ](https://www.amazon.com/GFS-Chemicals-48801-Magnesium-Hexahydrate/dp/B01NBML9XZ)
- Cheaper reagent-grade flake (98+%) options exist (~$15–$25/lb) e.g. [Amazon B087NY97ZM](https://www.amazon.com/Magnesium-Chloride-Hexahydrate-Bottles-Reagent/dp/B087NY97ZM). ACS grade preferred for reproducibility. **No institution required.** 500 g lasts effectively forever (you need millimolar).

### 3b. TAE buffer (folding + running buffer; "1×TAE + 12.5 mM MgCl₂" is the canonical origami buffer)
- **MP Biomedicals 50× TAE, 1 L** — Amazon, **~$54**. [Amazon B01MS22FJF](https://www.amazon.com/MP-Biomedicals-11TAE50X01-TAE-Buffer/dp/B01MS22FJF)
- Cheaper generic 50× TAE 1 L ~$20–$30: [Amazon B09V5MVMN9](https://www.amazon.com/50X-TAE-Buffer-Tris-Acetate-EDTA-1L/dp/B09V5MVMN9). 1 L of 50× → 50 L of 1×. Buying TAE premixed is far easier than buying Tris/acetic acid/EDTA separately, and the same price. **No institution required.**

### 3c. Agarose (for the folding-QC gel — you run an agarose gel to confirm a tight folded band)
- **Molecular-biology-grade agarose, 100 g** — Amazon, **~$30–$55** (RPI, Benchmark A1701, Bioworld/Apex generics). [RPI 100 g](https://www.amazon.com/RPI-Agarose-Molecular-Strength-Electrophoresis/dp/B00I31YMRU) · [Benchmark A1701 100 g](https://www.amazon.com/Benchmark-Scientific-A1701-Purified-Molecular/dp/B00XW1JREY). At ~1.5% gels, 100 g = dozens of gels. **No institution required.**

### 3d. DNA stain (visualize bands — use a safer EtBr alternative)
- **Biotium GelRed 10,000×, 0.5–1 mL** — **~$70–$110** (Biotium direct or resellers; also on Amazon/Sigma SCT123). [Biotium GelRed](https://biotium.com/product/gelred-nucleic-acid-gel-stain/) · [Sigma SCT123](https://www.sigmaaldrich.com/US/en/product/mm/sct123)
- Alternative: **SYBR Safe (Thermo S33102)** ~$80–$120. GelRed is the standard origami choice (non-mutagenic, post-stain or in-gel). 0.5 mL @ 10,000× = ~5 L of staining → many gels. **No institution required;** explicitly chosen because EtBr is the item a hobbyist should *avoid* (mutagen) and GelRed/SYBR Safe are the substitutes.

### 3e. Purification — remove excess staples after folding
Two real routes; **PEG is the hobbyist-friendly one.**
- **Route 1 — Amicon Ultra-0.5 mL, 100 kDa MWCO spin filters.** Spin-filter retains the assembled origami (MDa), washes out free staples. Millipore UFC510096 (100 kDa, 96-pack) on Amazon, **~$250–$350 for 96** (~$3/filter). [Amazon B004OYTK86](https://www.amazon.com/Millipore-Centrifugal-Ultracel-100-Purification-Concentration/dp/B004OYTK86) · [Sigma UFC5100](https://www.sigmaaldrich.com/US/en/product/mm/ufc5100). Needs a benchtop centrifuge (rig hardware). Single-use consumable. *This is the "lab-flavored" item — but it is openly Amazon-purchasable, no institution needed.*
- **Route 2 (cheaper, recommended for v0) — PEG precipitation.** Mix folded sample 1:1 with PEG precipitation buffer (1×TAE, **15% (w/v) PEG-8000**, ~500 mM NaCl, ~12 mM MgCl₂), spin, resuspend. Per **Stahl et al. 2014** (the canonical origami PEG protocol — see Claims). Consumable cost ≈ a jar of **PEG-8000 (~$25–$40, 500 g–1 kg, Amazon/laballey)** + NaCl (~$10) that lasts dozens of preps. Needs only a microcentrifuge. **No special filter consumable, no institution.**

### 3f. PCR/folding tubes & nuclease-free water (trivial, Amazon)
- **0.2 mL PCR 8-tube strips, DNase/RNase-free, ~125 strips** — Amazon, **~$12–$18**. [Amazon B09CVDBMQ9](https://www.amazon.com/PCR-Tubes-0-2ml-Strip-Included/dp/B09CVDBMQ9). (Folding happens in a thermocycler/heat-block in these tubes.)
- **Nuclease-free / molecular-biology-grade water, 1 L** — Amazon, **~$15–$25** (Quality Biological 351-029-131). [Amazon B07T14KWBZ](https://www.amazon.com/Quality-Biological-351-029-131-Molecular-Endotoxin/dp/B07T14KWBZ). Or make your own from distilled + autoclave; premixed is cheap enough. **No institution required.**
- **Micropipettes** (not strictly a consumable but needed to dispense µL): cheap adjustable-volume pipette sets (2–20 µL, 20–200 µL, 100–1000 µL) on Amazon **~$60–$120 for a 3-pipette set + tips**, e.g. generic "lab pipette set." Pipette *tips* (filter or standard, racked) are the recurring consumable, **~$15–$25 per 1,000**.

---

## 4. Honest total — ONE ~200-staple origami design

Splitting **one-time/reusable** (bought once, amortizes over many designs) from **per-design** (consumed each new design = the new staple set):

### Per-design recurring cost (the part that repeats for each NEW design)
| Item | Cheapest (oPool) | Standard (addressable plate) |
|---|---|---|
| ~200 staples | ~$200 (oPool) | ~$750 (IDT 25 nmol desalted plate) |
| Scaffold draw (per fold, amortized) | ~$5 (NEB) | ~$5 (NEB) |
| **Per-design total** | **~$205** | **~$755** |

### One-time / reusable starter kit (covers dozens of designs)
| Item | Price |
|---|---|
| Scaffold stock (NEB N4040, 10 µg) | $40 |
| MgCl₂ ACS 500 g | $35 |
| 50× TAE 1 L | $30 |
| Agarose 100 g | $40 |
| GelRed stain 0.5 mL | $90 |
| PEG-8000 500 g + NaCl (purification) | $45 |
| PCR strip tubes (125) | $15 |
| Nuclease-free water 1 L | $20 |
| Pipette tips (1,000) | $20 |
| **Reusable subtotal** | **~$335** |

### Bottom line
- **First design, cheap path (oPool + reusable kit):** **~$205 + ~$335 ≈ $540 all-in**, then **~$205 per additional known-shape design.**
- **First design, real-origami path (addressable plate + reusable kit):** **~$755 + ~$335 ≈ $1,090 all-in**, then **~$755 per additional custom design.**
- The reusable kit is bought once; from the 2nd design on, you only pay for new staples (+ ~$5 scaffold). **The staple synthesis is ~85–95% of marginal cost.** Optional Amicon filters add ~$300 if you prefer spin-filter over PEG.

---

## 5. Institution-required items & hobbyist substitutes

| "Lab-account" item | Required? | Hobbyist substitute |
|---|---|---|
| IDT / NEB account | **No** | Both take personal credit cards, ship residential. Verified. |
| Twist Bioscience | Soft-gated (MOQ/onboarding) | Use IDT oPools instead — same pooled-synthesis benefit, easy individual checkout. |
| Amicon 100 kDa spin filters | No (Amazon) | Or skip entirely: **PEG-8000 precipitation** (Stahl 2014) needs only a microcentrifuge + cheap reagents. |
| ACS-grade MgCl₂ | No | Reagent-grade flake from Amazon works; ACS just improves reproducibility. |
| EtBr (classic stain) | — (avoid) | **GelRed / SYBR Safe** — safer, Amazon-buyable, the actual community standard. |

**Net:** zero items in the consumable chain are gated behind an institution. The DNA reagents are unregulated standard mol-bio products; origami oligos are far too short to trip vendor biosecurity gene-screening.

---

## 6. Claims (peer-reviewed, verified)

1. **DNA origami: a single long scaffold folded by ~200 short staples yields a designed ~100 nm 2D shape (the "smiley") — demonstrated.**
   Rothemund, P. W. K. *Folding DNA to create nanoscale shapes and patterns.* **Nature** 440, 297–302 (2006). DOI: 10.1038/nature04586. https://www.nature.com/articles/nature04586 — *demonstrated=true.* This is the method's founding experimental paper; scope: ~100 nm planar shapes, not macroscopic.

2. **PEG (PEG-8000) precipitation purifies dense, pure DNA-origami solutions and removes excess staples — demonstrated.**
   Stahl, E.; Martin, T. G.; Praetorius, F.; Dietz, H. *Facile and Scalable Preparation of Pure and Dense DNA Origami Solutions.* **Angew. Chem. Int. Ed.** 53, 12735–12740 (2014). DOI: 10.1002/anie.201405991. https://onlinelibrary.wiley.com/doi/full/10.1002/anie.201405991 — *demonstrated=true.* Source of the 15% PEG-8000 / 500 mM NaCl / Mg²⁺ buffer used in §3e.

3. **Staple oligonucleotides dominate DNA-origami material cost, and staple recycling/reuse cuts that cost substantially — demonstrated.**
   Becker, F. et al. *Reusing excess staple oligonucleotides for economical production of DNA origami* (also published as *Cost-efficient folding ... via staple recycling*, **Nanoscale** 2025, DOI 10.1039/D5NR01435B). bioRxiv 2024.08.27.609958. https://www.biorxiv.org/content/10.1101/2024.08.27.609958v1.full — *demonstrated=true.* Reports ~33% staple-cost reduction over 5 reuse cycles (theoretical max ~41%), and that staples are the majority of fabrication cost — directly supports §4's "staples are 85–95% of marginal cost."

---

## 7. Notes / caveats for the compiler & rig team

- The shape→staple compiler (cadnano/scadnano output) must emit sequences against the **exact scaffold sequence you buy** (NEB M13mp18 = cadnano "M13mp18" = tilibit p7249 — these three are interchangeable; do **not** mix a p8064/p8634 design with a 7249 scaffold).
- Compiler should support **two export modes**: (a) IDT plate-spec `.xls`/IDT bulk-input format for addressable 25 nmol plates, and (b) a single concatenated sequence list for an **oPool** order — because that switch is the single biggest cost lever ($200 vs $750).
- Folding QC = agarose gel band + (ideally) AFM later; the consumables here cover the *gel* QC. AFM/imaging is rig hardware, out of scope for this doc.

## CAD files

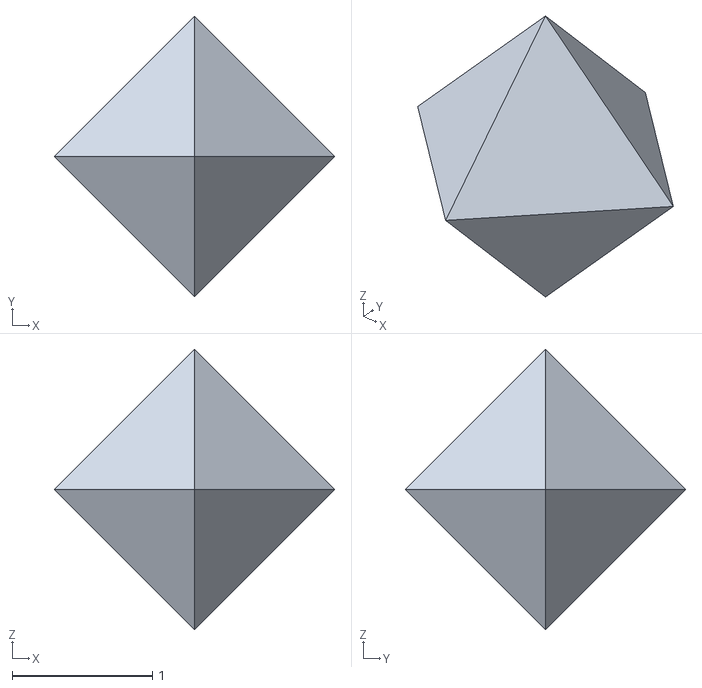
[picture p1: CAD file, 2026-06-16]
examples/octahedron.stl
2.00 x 2.00 x 2.00

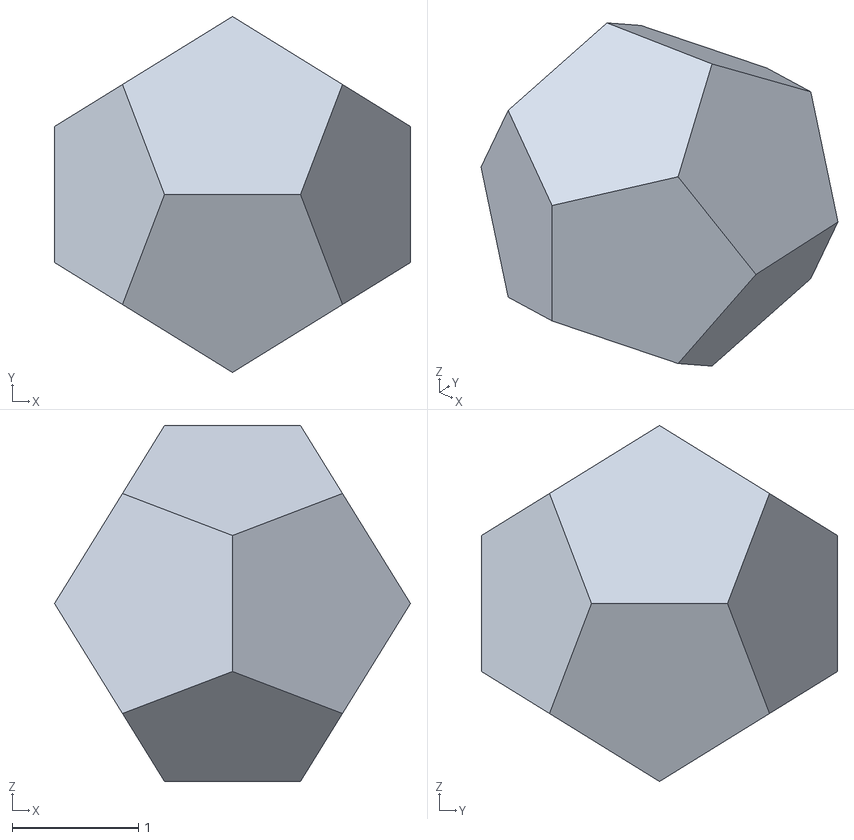
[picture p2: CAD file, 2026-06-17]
examples/out_dodecahedron/shape.ply
2.82 x 2.82 x 2.82

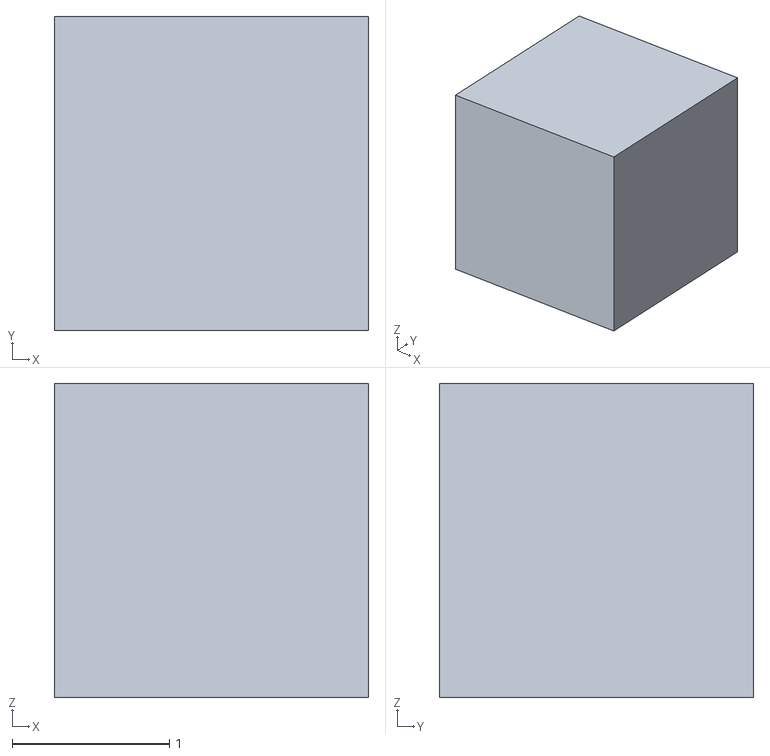
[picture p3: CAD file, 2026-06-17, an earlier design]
examples/out_cube/shape.ply
2.00 x 2.00 x 2.00

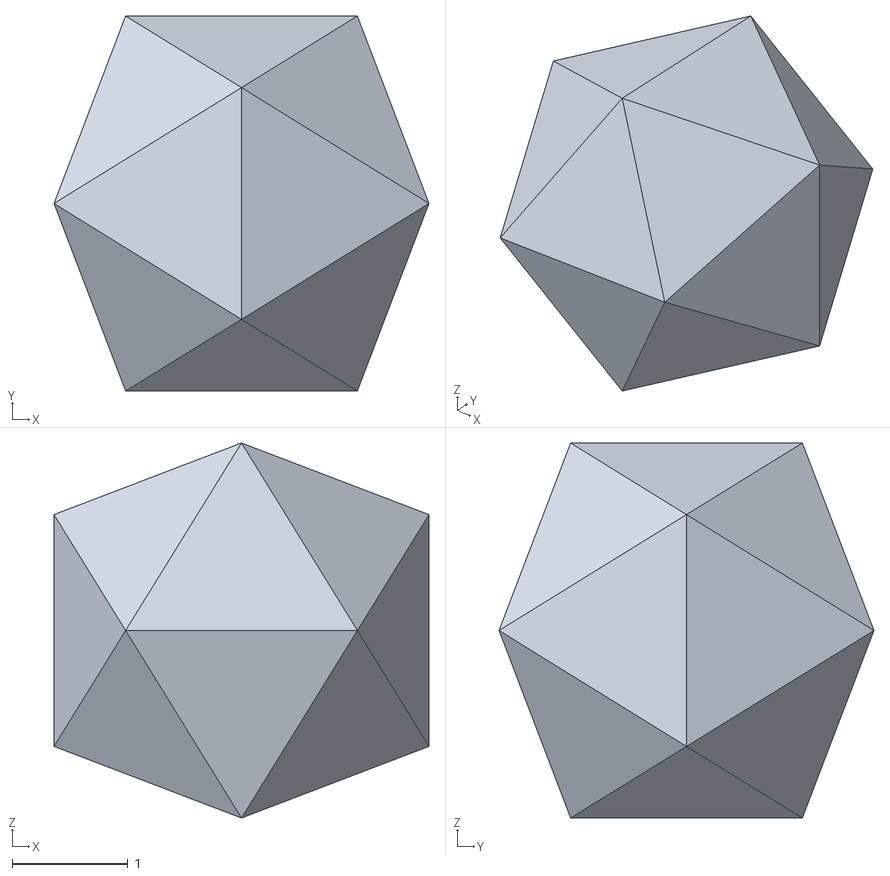
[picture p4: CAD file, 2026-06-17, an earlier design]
examples/out_icosahedron/shape.ply
3.24 x 3.24 x 3.24

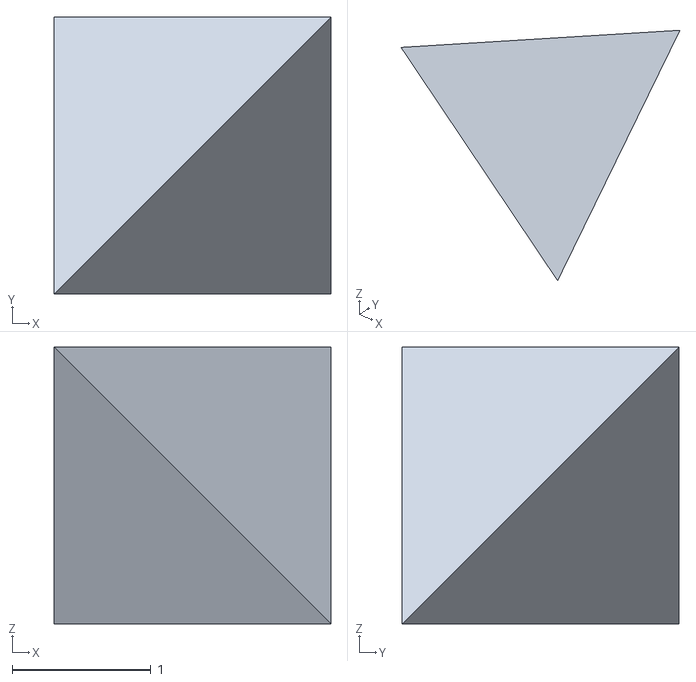
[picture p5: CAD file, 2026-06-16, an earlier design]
examples/out_tetrahedron/shape.ply
2.00 x 2.00 x 2.00

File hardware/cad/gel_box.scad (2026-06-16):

// Molecular Synth v0 - parametric DIY agarose gel-electrophoresis box
// ====================================================================
// Verify a fold: well-folded DNA origami runs as one tight band, distinct from
// the scaffold-only lane (Castro et al., Nat. Methods 2011; Stahl et al.,
// Angew. Chem. 2014). 3D-print this box (PLA/PETG), add stainless or platinum
// wire electrodes, run in 1x TAE + 12.5 mM MgCl2 at ~60-90 V on ice.
//
// Render the parts:  openscad -D part=\"buffer\" -o buffer.stl gel_box.scad
//                    part = \"buffer\" | \"tray\" | \"comb\" | \"all\"
//
// All dimensions in millimetres. Edit the parameters block to fit your gel size.

/* [Box] */
gel_len      = 80;    // casting tray inner length (run direction)
gel_wid      = 60;    // casting tray inner width
gel_thk      = 8;     // gel thickness
wall         = 3;     // wall thickness
buffer_extra = 22;    // electrode chamber length at each end
floor_thk    = 3;

/* [Comb] */
n_wells      = 8;
well_wid     = 5;
well_thk     = 1.2;   // tooth thickness -> well width in gel
comb_depth   = 6;     // how deep teeth dip into the gel
comb_handle  = 10;

/* [Electrodes] */
elec_d       = 1.6;   // wire / channel diameter (1.5 mm stainless TIG rod)
elec_z       = 4;     // height of electrode channel above floor

part = "all";

module buffer_chamber() {
    total_len = gel_len + 2*buffer_extra;
    total_wid = gel_wid + 2*wall;
    wall_h    = gel_thk + 12;
    difference() {
        // outer shell
        cube([total_len + 2*wall, total_wid, wall_h + floor_thk]);
        // inner cavity
        translate([wall, wall, floor_thk])
            cube([total_len, gel_wid, wall_h + 1]);
    }
    // casting-tray ledges (tray drops onto these, leaving electrode chambers open)
    for (x = [wall + buffer_extra, wall + buffer_extra + gel_len - 4])
        translate([x, wall, floor_thk])
            cube([4, gel_wid, 3]);
    // electrode channels (push wire through both side walls at each end)
    for (x = [wall + buffer_extra/2, wall + buffer_extra*1.5 + gel_len])
        translate([x, -1, floor_thk + elec_z])
            rotate([-90,0,0]) cylinder(h = total_wid + 2, d = elec_d, $fn=24);
}

module casting_tray() {
    difference() {
        cube([gel_len, gel_wid, gel_thk + floor_thk]);
        translate([wall, wall, floor_thk])
            cube([gel_len - 2*wall, gel_wid - 2*wall, gel_thk + 1]);
    }
    // open ends (dam removed before running) modelled as removable end caps
    // -> print two loose end dams:
    translate([0, gel_wid + 6, 0]) cube([2.5, gel_wid, gel_thk + floor_thk]);
    translate([6, gel_wid + 6, 0]) cube([2.5, gel_wid, gel_thk + floor_thk]);
}

module comb() {
    span = gel_wid - 2*wall - 6;
    pitch = span / n_wells;
    // handle bar
    translate([-2, 0, 0]) cube([well_thk + 4, span, comb_handle]);
    // teeth
    for (i = [0 : n_wells - 1])
        translate([0, i*pitch + (pitch - well_wid)/2, -comb_depth])
            cube([well_thk, well_wid, comb_depth + 1]);
}

if (part == "buffer" || part == "all") buffer_chamber();
if (part == "tray"   || part == "all") translate([0, -gel_wid - 20, 0]) casting_tray();
if (part == "comb"   || part == "all") translate([0, -gel_wid - 90, comb_depth]) comb();

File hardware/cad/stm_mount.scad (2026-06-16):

// Molecular Synth v0 - parametric DIY STM scanner mount (OPTIONAL track)
// =======================================================================
// Atomic-resolution capability demonstrator after Dan Berard's open-source STM:
// a piezo buzzer disk is the XYZ scanner, a hand-cut Pt/Ir wire is the tip, a
// transimpedance amplifier reads the ~nA tunnelling current, a Teensy/Arduino
// runs the feedback. A hobby STM reliably resolves the atomic lattice of HOPG
// graphite - it is NOT a direct imager of soft, hydrated DNA origami (use the gel
// for routine origami QC). See docs/research/04-verification-gel-stm.md.
//
// This prints the rigid base + magnetic coarse-approach ramp that the inchworm /
// screw advance pushes the sample toward the tip. Dimensions in mm; print rigid
// (PETG/ASA) and add mass (steel plate) for vibration isolation.
//
//   openscad -D part=\"base\" -o base.stl stm_mount.scad   // part = base|ramp|tip_holder|all

/* [Geometry] */
base_d      = 70;
base_h      = 10;
piezo_d     = 27;   // 27 mm piezo buzzer disk
piezo_pocket= 1.5;
ramp_angle  = 6;    // shallow coarse-approach incline
tip_arm_h   = 28;

part = "all";

module base() {
    difference() {
        cylinder(h = base_h, d = base_d, $fn=120);
        // piezo scanner pocket (center)
        translate([0,0,base_h - piezo_pocket])
            cylinder(h = piezo_pocket + 1, d = piezo_d + 0.6, $fn=80);
        // wire routing slot
        translate([0,0,base_h-3]) cube([base_d, 4, 4], center=true);
        // three M3 isolation-foot holes
        for (a = [0:120:240])
            rotate([0,0,a]) translate([base_d/2 - 7, 0, -1])
                cylinder(h = base_h + 2, d = 3.2, $fn=24);
    }
}

// Shallow coarse-approach wedge: the sample slides down it toward the tip.
module ramp() {
    l = 40; w = 18; h = l * tan(ramp_angle);
    rotate([90,0,0])
        linear_extrude(height = w)
            polygon([[0,0],[l,0],[l,h]]);
}

module tip_holder() {
    // arm that clamps the Pt/Ir tip over the piezo center
    difference() {
        union() {
            cube([8, 8, tip_arm_h]);
            translate([0,0,tip_arm_h-6]) cube([26, 8, 6]);
        }
        // tip channel (vertical) at the far end, over scanner center
        translate([22, 4, tip_arm_h-7]) cylinder(h=8, d=1.0, $fn=20);
        // mounting hole
        translate([4,4,-1]) cylinder(h=tip_arm_h+2, d=3.2, $fn=24);
    }
}

if (part == "base" || part == "all") base();
if (part == "ramp" || part == "all") translate([base_d/2+10,0,0]) ramp();
if (part == "tip_holder" || part == "all") translate([-base_d/2-15,0,0]) tip_holder();

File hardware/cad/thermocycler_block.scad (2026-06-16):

// Molecular Synth v0 - parametric Peltier folding-block enclosure
// ================================================================
// Stack (bottom -> top):  heatsink + fan  |  Peltier TEC1-12706 (40x40 mm)  |
// aluminium block drilled for 0.2 mL PCR tubes  |  this printed insulating collar
// + lid that clamps the stack and holds the NTC thermistor against the block.
//
// The Peltier is driven bidirectionally (BTS7960 H-bridge) by thermocycler.ino so
// the block both heats to 90 C and slow-cools to 20 C - the origami folding ramp.
// Print in PETG (better >60 C than PLA) or ASA. Dimensions in mm.
//
//   openscad -D part=\"collar\" -o collar.stl thermocycler_block.scad
//   part = \"collar\" | \"lid\" | \"all\"

/* [Peltier + block] */
pelt        = 40;     // Peltier edge (TEC1-12706 is 40x40x3.x mm)
block_x     = 40;
block_y     = 40;
block_h     = 18;     // aluminium block height
wall        = 4;
collar_h    = 22;

/* [Tube holes - for reference / a printable block if no aluminium] */
n_tubes     = 6;
tube_top_d  = 6.2;    // 0.2 mL tube top dia
tube_bot_d  = 2.8;
tube_depth  = 16;

/* [Thermistor] */
therm_d     = 4.2;    // channel for a glass-bead/epoxy NTC

part = "all";

module insulating_collar() {
    difference() {
        cube([block_x + 2*wall, block_y + 2*wall, collar_h]);
        // pocket the aluminium block sits in
        translate([wall, wall, wall])
            cube([block_x, block_y, collar_h]);
        // thermistor channel into the block pocket from the side
        translate([-1, wall + block_y/2, wall + block_h/2])
            rotate([0,90,0]) cylinder(h = wall + 2, d = therm_d, $fn=24);
        // wire exit slot
        translate([block_x/2, -1, collar_h-5]) cube([8, wall+2, 6]);
    }
}

module clamp_lid() {
    difference() {
        cube([block_x + 2*wall, block_y + 2*wall, wall + 6]);
        // tube access holes (align over the aluminium block bores)
        span = block_x - 8;
        pitch = span / n_tubes;
        for (i = [0 : n_tubes-1])
            translate([wall + 4 + i*pitch, block_y/2 + wall, -1])
                cylinder(h = wall + 8, d = tube_top_d, $fn=32);
    }
}

// Optional: a fully-printable aluminium-free block is NOT recommended (plastic is a
// poor conductor); use a drilled aluminium bar. This module documents the bore map.
module reference_block() {
    difference() {
        cube([block_x, block_y, block_h]);
        span = block_x - 8;
        pitch = span / n_tubes;
        for (i = [0 : n_tubes-1])
            translate([4 + i*pitch, block_y/2, block_h - tube_depth + 0.1])
                cylinder(h = tube_depth + 1, d1 = tube_bot_d, d2 = tube_top_d, $fn=32);
    }
}

if (part == "collar" || part == "all") insulating_collar();
if (part == "lid"    || part == "all") translate([0, -block_y - 20, 0]) clamp_lid();
if (part == "block_ref") reference_block();

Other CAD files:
examples/out_octahedron/shape.ply

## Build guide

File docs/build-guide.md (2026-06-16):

# BUILD GUIDE — from an empty bench to a folded nanostructure

This is the full blueprint: order → build the rig → install the software → **validate
the rig on a known design** → fold your own compiled design → verify → (optionally)
harden to silica. Everything uses parts orderable online today; the rig is < $1500
([`../bom/bom.md`](../bom/bom.md)).

> **What you will actually make:** a DNA-origami nanostructure, ~10–100 nm, in ~10¹²
> copies per reaction, verified as a folded band on a gel and (optionally) converted to
> rigid silica. **Not** a macroscopic object, **not** diamondoid — see
> [`science.md`](science.md) / [`north-star.md`](north-star.md). This is the real,
> demonstrated first rung; the guide keeps you on it.

**Total to first verified fold:** ≈ $623 rig (one-time) + ≈ $540 consumables
(first design, oPool path) ≈ **$1.16k all-in**, then ≈ $205 per additional design.
Calendar time ≈ **2–4 weeks** (mostly oligo + scaffold shipping), **~2 active days**
of bench work.

---

## Phase 0 — Decide & order (Day 0; then wait on shipping)

1. **Order the rig hardware** ([`bom.json`](../bom/bom.json), category `rig-hardware`,
   ≈ $623): Peltier + BTS7960 H-bridge + Arduino + thermistor + aluminium block + 12 V
   PSU + heatsink (thermocycler ≈ $108); IVYX gel system + blue transilluminator
   (≈ $290); vortex + mini-centrifuge (≈ $135); micropipette set (≈ $90).
2. **Order consumables** (category `consumable`, ≈ $540 first design): M13mp18 scaffold
   (NEB N4040, $40); **a published, known-good staple set as an oPool** (see Phase 4) —
   this is your rig-validation reagent; MgCl₂, 50× TAE, agarose, GelGreen, DNA ladder,
   PEG-8000, PCR tubes, nuclease-free water (reusable kit ≈ $330).
3. While you wait: build the rig (Phases 1–2) and install the software (Phase 3).

> **Sourcing reality:** IDT and NEB sell to individuals with a credit card and ship to
> residential addresses; origami oligos (32–42 nt) are far below any gene-synthesis
> screening threshold. Nothing here needs an institutional account.

---

## Phase 1 — Build the folding thermocycler (~½ day)

Stack: CPU heatsink+fan → Peltier (TEC1-12706) → drilled aluminium block (0.2 mL tube
bores) → printed insulating collar ([`../hardware/cad/thermocycler_block.scad`](../hardware/cad/thermocycler_block.scad)).
Thermal-paste each interface. Hold the thermistor in the block (collar channel).

Wiring (see [`../hardware/README.md`](../hardware/README.md)):
```
12V 30A PSU ─┬─► BTS7960 H-bridge ─► Peltier   (reversible: heat AND cool)
             └─► CPU fan (always on)
Arduino Uno:  D9→H-bridge PWM(EN)   D7/D8→direction(heat/cool)   D5→fan
              A0→100k NTC thermistor (4.7k pull-up to 5V)
```
Flash [`../hardware/firmware/thermocycler.ino`](../hardware/firmware/thermocycler.ino)
(Arduino IDE → Uno → Upload). **Bench test before any DNA:** open the serial monitor
@115200, send `SET 60`, confirm the block reaches ~60 °C and holds; send `SET 90`
then watch it cool to `SET 20` — the H-bridge must actively cool, not just coast. The
firmware has a hard 99 °C cutoff. *No-electronics alternative:* a sous-vide bath +
manual setpoint steps.

---

## Phase 2 — Build the gel verification rig (~1–2 hr)

Easiest: the IVYX all-in-one (tank + integrated 50/100 V supply). DIY alternative:
print [`../hardware/cad/gel_box.scad`](../hardware/cad/gel_box.scad), add stainless/Pt
wire electrodes, and supply 60–90 V. **Critical:** origami gels need **Mg²⁺ in the gel
and running buffer** (1× TAE + ~11 mM MgCl₂) and must run **cold** (on ice), or the
origami unfolds. A 0–30 V bench supply is **not** enough — use 50–100 V.

---

## Phase 3 — Install the software & compile a design (~15 min)

```bash
cd compiler
python -m molsynth compile tetrahedron --out out/tetra      # pure stdlib, no installs
# optional extras (real M13 fetch, scadnano export, STL):
pip install -r requirements.txt
python -m molsynth fetch-scaffold
```
Outputs in `out/tetra/`: `staples.csv` (+ `staples_idt_plate.txt` / `staples_opool.txt`
to order), `protocol.md` (the recipe), `diagnostics.md` (predicted yield), and the 3D
structure `conf.dat`/`structure.pdb` — open `conf.dat` in
[oxView](https://sulcgroup.github.io/oxdna-viewer/) to *see* the design and relax it in
[oxDNA](https://lorenzo-rovigatti.github.io/oxDNA/) before spending money.

---

## Phase 4 — VALIDATE THE RIG on a known design FIRST (do not skip)

Before trusting any novel compiled design, prove the **rig** works with a
**published, known-to-fold** structure. Recommended: the **Rothemund rectangle** or a
**published wireframe tetrahedron** (DAEDALUS/PERDIX) whose staple set is in the paper's
supplement. Order that exact staple set (as an oPool) + the matching scaffold, fold it
per Phase 5, and confirm a clean gel band (Phase 6). This separates *rig faults* from
*design faults* — the single most important discipline for making this real. Only once
the rig reproduces a published design do you trust your own compiled outputs.

---

## Phase 5 — Fold (one anneal, ~2–20 h)

Follow the auto-emitted `protocol.md` for your design. In short: mix scaffold (~20 nM)
+ staples (5–10× each) in 1× TAE + 12.5 mM MgCl₂ (≈50 µL in a PCR tube); run the anneal
ramp on the thermocycler:
```bash
python ../hardware/firmware/host_ramp.py --design out/tetra/design.json --port COM3
```
Heat ~90 °C → slow-cool ~20 °C. Simple 2D folds in ~2 h; stiff 3D wants a longer ramp
and a per-design Mg²⁺ × ramp screen (the protocol lists the screen grid).

---

## Phase 6 — Verify on the gel (~2–3 h, cold)

Cast 1.5–2 % agarose in 1× TAE + ~11 mM MgCl₂. Load: (a) your folded sample, (b) a
**scaffold-only control**, (c) a **ladder**. Run 60–90 V on ice, stain GelGreen, image
on the blue transilluminator. **Read-out:** a well-folded origami is one **tight band**
that migrates *differently from the scaffold-only lane*; smear / well-stuck material =
aggregation/misfolding → slow the ramp or retune Mg²⁺. (Gel tells folded-vs-not, not nm
shape — shape confirmation needs AFM/TEM, out of the desktop budget.)

---

## Phase 7 — (Optional) Purify & harden to silica

- **Purify:** PEG-8000 precipitation (15 % PEG / 500 mM NaCl / Mg²⁺), spin in the
  mini-centrifuge, resuspend — removes excess staples (Stahl 2014).
- **Harden (fume hood):** incubate purified origami with an aminosilane (TMAPS/APTES)
  then TEOS in the Mg²⁺ buffer, days at RT → a rigid **silica replica** (Liu 2018). This
  is the step that turns the soft template into a durable, dryable, imageable object.
  TEOS/methanol are flammable — ventilate.

---

## Phase 8 — (Optional) Atomic-resolution demo (STM)

Build the DIY STM ([`../hardware/cad/stm_mount.scad`](../hardware/cad/stm_mount.scad))
and resolve the **HOPG graphite atomic lattice** — proof that single-atom imaging is a
desktop-cheap reality. Honest note: this images graphite atoms, **not** your origami
(that needs AFM/cryo-TEM). It's the "atomic resolution is real" trophy, decoupled from
product QC.

---

## Troubleshooting

| Symptom | Likely cause | Fix |
|---|---|---|
| No band / everything in the well | aggregation; Mg²⁺ too high or ramp too fast | lower Mg²⁺ (try 8–12.5 mM), slow the ramp |
| Only a fast diffuse front | only staples; scaffold didn't fold | check scaffold conc/quality; verify staple:scaffold ratio |
| Band same as scaffold-only | no folding | confirm staples present & correct scaffold (p7249 vs p8064) |
| Block won't cool | H-bridge wired one-way | confirm D7/D8 direction pins; the Peltier must reverse |
| Smeary/streaky gel | gel warmed up | run colder / lower voltage; Mg²⁺ in the running buffer |

## Safety
Flammable silane/alcohol → fume hood. GelGreen (not EtBr). Gel runs at 60–90 V — fuse
and insulate. 12 V/30 A Peltier supply — appropriate gauge wire. Follow local rules.

## What "reality" means here
You will have **manufactured atomically-defined, sequence-addressed matter at the
nanoscale on a desk for ~$1k**, designed by your own one-command compiler, verified by
gel, optionally hardened to silica. That is real, demonstrated nanofabrication. It is
the first rung — not the macroscopic matter compiler. The ambition stays honestly on the
[north-star track](north-star.md) until the chemistry that would extend it is itself
demonstrated.

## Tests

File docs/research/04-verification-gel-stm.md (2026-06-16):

# Domain 04 — Verification: Did the product fold? What does it look like?

**Project:** Molecular Synth v0 — desktop DNA-origami nanofabrication rig + shape→staple compiler.
**This domain:** *Quality control / verification* of the assembled product. Two independent tracks:

1. **DIY agarose gel electrophoresis** — the workhorse, honest QC tool. A correctly folded origami runs as a tight, fast band distinct from leftover staples (small, runs ahead) and aggregates/misfolds (large/smeared, runs behind or stuck in the well). This is real, in-budget, and is exactly how origami labs do first-pass QC.
2. **DIY scanning tunneling microscope (STM)** — an *atomic-resolution capability demonstrator*. A hobby STM (Dan Berard / Open-STM design) reliably resolves the atomic lattice of HOPG (graphite) in air. **It does NOT image a soft DNA origami in solution.** It is included as proof that atomic-scale imaging is achievable on a hobby budget — a north-star instrument — NOT as the origami QC tool. Be honest about this everywhere.

---

## TRACK 1 — Agarose gel electrophoresis (the real QC method)

### Why this is the right tool
Agarose gel electrophoresis separates DNA by size/conformation under an electric field. For scaffolded DNA origami:
- **Well-folded monomer** → compact, high mobility → one tight leading band.
- **Excess staple strands** (the 200+ short oligos added in excess) → tiny, run far ahead as a diffuse front.
- **Aggregates / misfolds / multimers** → larger/slower, smear, or stick in the loading well.

Comparing the folded-sample lane against the raw scaffold lane (e.g. M13mp18, ~7,249 nt) tells you at a glance whether folding worked. This is standard practice and is documented in the canonical origami protocols below.

### Scientific citations (all verified via web search)

1. **Rothemund, P. W. K.** "Folding DNA to create nanoscale shapes and patterns." *Nature* 440, 297–302 (2006). DOI: 10.1038/nature04586. https://www.nature.com/articles/nature04586
   - The origin of scaffolded DNA origami. **Demonstrated = true** (AFM images of folded shapes ~100 nm). Establishes the whole product category. Scope: 2D shapes ~100 nm, AFM-verified.

2. **Castro, C. E.; Kilchherr, F.; Kim, D.-N.; Shiao, E. L.; Wauer, T.; Wortmann, P.; Bathe, M.; Dietz, H.** "A primer to scaffolded DNA origami." *Nature Methods* 8, 221–229 (2011). DOI: 10.1038/nmeth.1570. https://www.nature.com/articles/nmeth.1570
   - The practical "how-to" reference. **Its Supplementary Protocol 3 is literally "Agarose Gel Electrophoresis (EtBr) with DNA origami objects."** This is the citation that grounds gel-based origami QC. **Demonstrated = true** (gels + TEM of 3D objects). Scope: describes gel conditions (≈2% agarose, ~11 mM MgCl₂ in running buffer, ~70 V, ice-cooled) and folding-quality readout.

3. **Stahl, E.; Martin, T. G.; Praetorius, F.; Dietz, H.** "Facile and Scalable Preparation of Pure and Dense DNA Origami Solutions." *Angew. Chem. Int. Ed.* 53(47), 12735–12740 (2014). DOI: 10.1002/anie.201405991. https://onlinelibrary.wiley.com/doi/10.1002/anie.201405991 (open access PMC: https://pmc.ncbi.nlm.nih.gov/articles/PMC4253120/)
   - Purification of folded origami. The headline method is **PEG (poly-ethylene-glycol) precipitation**, but the paper benchmarks purity against **gel-based purification/QC** and is the standard citation for getting pure, dense origami after folding. **Demonstrated = true.** Scope note: PEG precipitation is the *scalable* purification; gel excision is the classic small-scale purification. Both rely on the gel as the readout of what's folded.

### Honest scope of Track 1
- A gel tells you **folded vs. not-folded and roughly monodisperse vs. aggregated**. It does **NOT** tell you the *shape* or give nm-resolution images. Shape confirmation needs AFM/TEM (out of hobby budget). The gel is necessary-but-not-sufficient first-pass QC — and it's the single most valuable cheap instrument in the whole rig.
- Origami gels are run **cold** (on ice / in a fridge) and need **Mg²⁺ in the running buffer** (origami falls apart without ~10 mM Mg²⁺). Plain TAE alone is for the scaffold control; origami lanes need TAE + ~11 mM MgCl₂. This is a real gotcha the compiler/protocol docs must surface.

### Voltage note (load-bearing)
Origami gels run at **~60–90 V** for 1.5–3 h, cold. A standard adjustable **0–30 V** bench supply is therefore **NOT sufficient** for the gel. Options, in order of preference:
- Use the **gel kit's own integrated power supply** (the IVYX mini system supplies 35/50/100 V presets — 50 V or 100 V both usable).
- Or a dedicated electrophoresis power supply.
- Or a boost-converter / stacked-battery rig (DIY, riskier).
Do **not** spec a 0–30 V bench unit as the gel driver — it will not push origami through 2% agarose in reasonable time.

### Parts — Track 1 (gel)

| Part | Role | Vendor | ~Price | Category | Notes |
|---|---|---|---|---|---|
| IVYX Scientific Mini Gel Electrophoresis System (tank + integrated 35/50/100 V supply + 2 casting sets + combs) | Complete gel rig incl. power supply at origami-compatible 50–100 V | Amazon (IVYX) | ~$160 | rig-hardware | All-in-one; the integrated supply solves the 60–90 V requirement. https://www.amazon.com/Electrophoresis-System-Power-Supply-Timer/dp/B0B2ZSRG2Z |
| Frey Scientific Single-Gel Apparatus (platinum electrodes, acrylic tank, 12-well combs) — *alternative tank* | Acrylic casting/run tank with Pt electrodes (needs external supply) | Amazon | ~$70 | optional | Pt electrodes, but power supply NOT included; pair with the IVYX or a 100 V supply. https://www.amazon.com/Frey-Scientific-1267918-Single-Gel-Electrophoresis/dp/B008C4PAKG |
| Blue LED Transilluminator, 470 nm | Visualize GelRed/GelGreen/SYBR-stained bands (blue light = eye/skin safe, no UV) | Amazon | ~$130 | rig-hardware | Blue-light is the hobbyist-safe choice; pairs with green dyes. https://www.amazon.com/Light-Transilluminator-470nm-Electrophoresis-Visualization/dp/B0B2ZDFM8D |
| GelGreen Nucleic Acid Gel Stain, 10,000X, 0.5 mL (Biotium) | DNA-safe fluorescent stain (replaces ethidium bromide; non-mutagenic, drain-disposable) | Amazon (Biotium) | ~$110 | consumable | Optimized for blue-light transilluminator. https://www.amazon.com/GelGreen-Nucleic-Acid-Stain-Water/dp/B07RY6BJMT |
| 50X TAE Buffer concentrate, 1 L | Running/gel buffer (dilute to 1X; add MgCl₂ for origami lanes) | Amazon | ~$25 | consumable | https://www.amazon.com/50X-TAE-Buffer-Tris-Acetate-EDTA-1L/dp/B09V5MVMN9 |
| Agarose, Molecular Biology Grade, 100 g | Gel matrix (run ~2% for origami) | Amazon | ~$45 | consumable | https://www.amazon.com/Agarose-Molecular-Biology-Grade-P05-SR01-100/dp/B00S9ZJFLI |
| DNA Ladder (100 bp – 1 kb) | Size marker lane | Amazon (IVYX) | ~$40 | consumable | https://www.amazon.com/IVYX-Scientific-Ladders-Electrophoresis-100bp/dp/B0GPMJCW2Q |

*MgCl₂ (for ~11 mM in origami running buffer) is a cheap commodity reagent and should be added to the consumables list separately.*

---

## TRACK 2 — DIY STM (atomic-resolution capability demonstrator)

### What it is and is NOT
- **IS:** A working scanning tunneling microscope built from a cut piezo buzzer (quadrant scanner), a hand-cut Pt/Ir (or W) tip, a transimpedance amplifier (current-to-voltage), an Arduino/Teensy controller, and vibration isolation. On **conductive HOPG (graphite)** in air it resolves the **atomic lattice** — individual carbon atom positions.
- **IS NOT:** A tool that images DNA origami. Origami is soft, insulating, ~10–100 nm tall, and sits in aqueous Mg²⁺ buffer. A hobby air-STM cannot image it. (Lab origami imaging uses AFM in liquid or cryo-TEM — out of budget.) **Frame the STM honestly as the "we can resolve single atoms on a desktop" demonstrator / north-star instrument, not the QC path for the product.**

### Scientific / design citations (all verified)

4. **Berard, D.** Open-source "Scanning Tunneling Microscope" (Hackaday.io project #4986, 2015). https://hackaday.io/project/4986-scanning-tunneling-microscope
   - The canonical hobby STM. Uses a **piezo buzzer cut into quadrants** as the scanner, a **tip cut from tungsten/Pt-Ir wire**, sapphire tip mount, fine Z screws. **Demonstrated = true** — Berard imaged **HOPG with atomic resolution in air**. Scope: images the graphite lattice; does NOT image soft/biological samples. (Project page is not peer-reviewed, but the result is reproduced in the peer-reviewed Open-STM paper below.)

5. **Ma, W. (Institute of Optics and Electronics, Chinese Academy of Sciences).** "Open STM: A low-cost scanning tunneling microscope with a fast approach method." *HardwareX* 17, e00504 (2023). DOI: 10.1016/j.ohx.2023.e00504. https://www.hardware-x.com/article/S2468-0672(23)00111-6/fulltext (open access: https://pmc.ncbi.nlm.nih.gov/articles/PMC10825635/)
   - **Peer-reviewed** open-hardware STM, total cost **~$300 / 2000 CNY**, control voltage ≤15 V, 45×45×31.5 mm. **Demonstrated = true** — imaged **HOPG and resolved atomic features** at 50–60 mV bias. This is the citation that makes "hobby STM resolves the atomic lattice" a peer-reviewed claim, not just a hobbyist blog. Scope: HOPG / conductive flat samples only; not biological, not in liquid.

### Honest scope of Track 2
- **demonstrated = true** for "resolves HOPG atomic lattice on a ~$300 desktop build."
- **demonstrated = false / N-A** for any claim that the STM images the DNA origami product. State plainly: the STM and the origami never touch the same sample. It is the "atomic-resolution is real and cheap" trophy, decoupled from product QC.

### Parts — Track 2 (STM)

| Part | Role | Vendor | ~Price | Category | Notes |
|---|---|---|---|---|---|
| Piezo buzzer disc, 27 mm (multi-pack) | Cut into quadrants → XYZ scanner (the Berard trick) | Amazon | ~$9 (15-pack) | rig-hardware | Repurposed from doorbell/alarm buzzers. https://www.amazon.com/15-Pieces-Elements-Electrode-Oscillator/dp/B00DH2UKYO |
| Platinum/Iridium wire, 0.25 mm, 90:10 Pt:Ir, ~30 cm | Hand-cut STM tip (1 length → ~50 tips) | Surepure Chemetals / Nanosurf | ~$60 | consumable | https://www.surepure.com/Platinum-Iridium-Wire-Rod-90-Percent-Platinum-10-Percent-Iridium/a/1432,1,815 (or Nanosurf https://shop.nanosurf.com/products/accessories/pt-ir-wire,-0-25mm-30cm) |
| HOPG sample (Grade B, 5×5×1 mm) | The conductive test specimen whose atomic lattice the STM resolves | Amazon | ~$90 | consumable | https://www.amazon.com/Oriented-Pyrolytic-Graphite-Priority-Shipping/dp/B08D94B6JW (cheaper grade B is fine for atomic imaging; ZYH lab grade from MSE Supplies is the upgrade) |
| Teensy 4.0 microcontroller | Real-time scan control / DAC-ADC loop | Adafruit / SparkFun / PJRC | ~$25 | rig-hardware | https://www.adafruit.com/product/4323 |
| LF356 JFET-input op-amp (DIP-8) | Transimpedance amplifier — converts pA–nA tunneling current to voltage | Mouser / DigiKey / Amplified Parts | ~$2 | rig-hardware | JFET input = low bias current, needed for tunneling currents. https://www.mouser.com/c/?series=LF356 (datasheet TI: https://www.ti.com/product/LF356). OPA129/OPA111 are higher-end upgrades. |

**Additional STM consumables (commodity, list separately):** high-value feedback resistor (~100 MΩ for the TIA), sapphire/ceramic tip mount, fine-pitch Z adjustment screws, and a vibration-isolation stack (bungee + stacked steel plates + Sorbothane — all repurposed hardware, well under $50).

---

## Budget roll-up (rig hardware only; target < $1500)

| Track | Rig-hardware items | Subtotal |
|---|---|---|
| Gel | IVYX gel system ($160) + blue transilluminator ($130) | ~$290 |
| STM | piezo buzzer ($9) + Teensy ($25) + LF356 ($2) | ~$36 |
| **Total rig hardware** | | **~$326** |

Consumables (counted separately): GelGreen (~$110), TAE (~$25), agarose (~$45), DNA ladder (~$40), Pt/Ir wire (~$60), HOPG (~$90), MgCl₂ + TIA resistor + tip mount + isolation (~$50). Consumables ≈ **$420**.

Both tracks together come in **far under the $1500 rig budget** — the verification domain is the cheapest part of the whole Molecular Synth v0.

---

## Compiler / software facts (for the shape→staple toolchain to surface)
- **Gel readout logic:** folded origami = tight leading band; staples = fast diffuse front; aggregate/misfold = smear or well-stuck slow band. Always run a **scaffold-only control lane** (M13mp18, ~7,249 nt) and a **ladder lane** for comparison.
- **Origami gel running buffer needs Mg²⁺** (~11 mM MgCl₂ in 1× TAE); without it origami unfolds. Plain 1× TAE only for the scaffold control. The compiler's protocol export must emit this buffer recipe.
- **Gel conditions:** ~2% agarose, ~60–90 V, **run cold (on ice / in fridge)**, GelGreen stain, blue-light (470 nm) visualization. Run 1.5–3 h.
- **STM controller:** Teensy 4.0 firmware (Arduino IDE / Teensyduino), real-time PID feedback holding constant tunneling current; bias ~50–60 mV for HOPG; control voltages ≤15 V (per Open-STM). Transimpedance amp = LF356 with ~100 MΩ feedback. Image data is an XY raster of Z-height → render as PNG/heightmap.
- **Honest separation in software/UX:** the STM module is a separate "atomic-imaging demo" feature; the **gel module is the product-QC feature.** Do not let the UI imply the STM verifies the origami.

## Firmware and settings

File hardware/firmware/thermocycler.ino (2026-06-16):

/*
 * Molecular Synth v0 - DNA origami folding thermocycler firmware
 * ---------------------------------------------------------------
 * Repurposed parts (see /bom):
 *   - Peltier TEC1-12706 thermoelectric module (CPU/cooler/dehumidifier part)
 *   - BTS7960 / IBT-2 H-bridge motor driver  -> bidirectional Peltier drive (heat AND cool)
 *   - 100k NTC thermistor (3D-printer hot-end part) on the aluminium tube block
 *   - 12 V supply from a repurposed PC/laptop PSU
 *   - Arduino Uno/Nano
 *
 * Function: closed-loop PID tracks a setpoint; the host streams the anneal ramp
 * emitted by the compiler (design.json -> host_ramp.py), so the SAME ramp that the
 * wet-lab protocol prints is what the block executes. Heat 90 C, then slow-cool to
 * 20 C in Mg2+ buffer = standard scaffolded-origami folding (Rothemund 2006; Castro
 * et al., Nat. Methods 2011).
 *
 * Serial protocol @ 115200 (newline-terminated):
 *   SET <tempC>        set target temperature, hold indefinitely
 *   STEP <tempC> <sec> ramp/hold to tempC for <sec> seconds, then report DONE
 *   STATUS             print "T=<meas> SP=<set> OUT=<-255..255>"
 *   STOP               output 0, hold
 * Without a host, RUN_DEFAULT_RAMP=1 executes a built-in 90->20 C ramp on boot.
 */

#include <Arduino.h>

// ---- pins ----
const int PIN_THERM   = A0;   // NTC divider midpoint
const int PIN_PWM     = 9;    // H-bridge enable/PWM
const int PIN_DIR_HOT = 7;    // H-bridge direction A (heat)
const int PIN_DIR_COLD= 8;    // H-bridge direction B (cool)
const int PIN_FAN     = 5;    // heatsink fan (always on while running)

// ---- thermistor (Beta model) ----
const float SERIES_R   = 100000.0;  // divider resistor (ohms)
const float THERM_NOM  = 100000.0;  // thermistor nominal R at 25 C
const float THERM_BETA = 3950.0;
const float TEMP_NOM_K = 298.15;
const float ADC_MAX    = 1023.0;

// ---- PID ----
float Kp = 18.0, Ki = 0.35, Kd = 30.0;
float integ = 0, prevErr = 0;
float setpoint = 25.0;
unsigned long lastPid = 0;
const unsigned long PID_MS = 200;

// ---- safety ----
const float T_MAX = 99.0;     // hard cutoff; DNA/buffer must not boil over
const float T_MIN = 2.0;

// ---- default ramp (used if no host) ----
#define RUN_DEFAULT_RAMP 1
struct Step { float tempC; unsigned long sec; };
Step defaultRamp[] = {
  {90, 300}, {85, 514}, {80, 514}, {75, 514}, {70, 514}, {65, 514},
  {60, 514}, {55, 514}, {50, 514}, {45, 514}, {40, 514}, {35, 514},
  {30, 514}, {25, 514}, {20, 514}
};
const int defaultRampLen = sizeof(defaultRamp) / sizeof(defaultRamp[0]);

float readTempC() {
  // average a few samples
  long acc = 0;
  for (int i = 0; i < 8; i++) acc += analogRead(PIN_THERM);
  float adc = acc / 8.0;
  if (adc <= 0) adc = 0.5;
  float r = SERIES_R * (ADC_MAX / adc - 1.0);   // thermistor on top of divider
  float invT = 1.0 / TEMP_NOM_K + (1.0 / THERM_BETA) * log(r / THERM_NOM);
  return (1.0 / invT) - 273.15;
}

void drive(float out) {  // out in [-255, 255]; + = heat, - = cool
  if (out > 255) out = 255; if (out < -255) out = -255;
  if (out >= 0) {
    digitalWrite(PIN_DIR_HOT, HIGH); digitalWrite(PIN_DIR_COLD, LOW);
    analogWrite(PIN_PWM, (int)out);
  } else {
    digitalWrite(PIN_DIR_HOT, LOW); digitalWrite(PIN_DIR_COLD, HIGH);
    analogWrite(PIN_PWM, (int)(-out));
  }
}

float pidStep(float meas) {
  float err = setpoint - meas;
  integ += err * (PID_MS / 1000.0);
  integ = constrain(integ, -400, 400);
  float deriv = (err - prevErr) / (PID_MS / 1000.0);
  prevErr = err;
  return Kp * err + Ki * integ + Kd * deriv;
}

void serviceControl() {
  unsigned long now = millis();
  if (now - lastPid < PID_MS) return;
  lastPid = now;
  float t = readTempC();
  if (t > T_MAX || t < T_MIN) { drive(0); return; }   // fault -> coast
  drive(pidStep(t));
}

void rampTo(float tempC, unsigned long sec) {
  setpoint = constrain(tempC, T_MIN, T_MAX);
  unsigned long t0 = millis();
  while (millis() - t0 < sec * 1000UL) {
    serviceControl();
    if (Serial.available()) return;   // host can interrupt
  }
}

void setup() {
  Serial.begin(115200);
  pinMode(PIN_PWM, OUTPUT); pinMode(PIN_DIR_HOT, OUTPUT);
  pinMode(PIN_DIR_COLD, OUTPUT); pinMode(PIN_FAN, OUTPUT);
  digitalWrite(PIN_FAN, HIGH);
  drive(0);
  Serial.println(F("molsynth-thermocycler ready"));
#if RUN_DEFAULT_RAMP
  if (!Serial.available()) {
    Serial.println(F("RUN default ramp 90->20C"));
    for (int i = 0; i < defaultRampLen; i++) {
      Serial.print(F("STEP ")); Serial.print(defaultRamp[i].tempC);
      Serial.print(F(" ")); Serial.println(defaultRamp[i].sec);
      rampTo(defaultRamp[i].tempC, defaultRamp[i].sec);
    }
    Serial.println(F("DONE default ramp"));
  }
#endif
}

String buf;
void loop() {
  serviceControl();
  while (Serial.available()) {
    char c = Serial.read();
    if (c == '\n') {
      buf.trim();
      if (buf.startsWith("SET ")) {
        setpoint = buf.substring(4).toFloat();
        Serial.print(F("OK SET ")); Serial.println(setpoint);
      } else if (buf.startsWith("STEP ")) {
        int sp = buf.indexOf(' ', 5);
        float tc = buf.substring(5, sp).toFloat();
        unsigned long sec = (unsigned long) buf.substring(sp + 1).toInt();
        rampTo(tc, sec);
        Serial.println(F("DONE"));
      } else if (buf == "STATUS") {
        Serial.print(F("T=")); Serial.print(readTempC());
        Serial.print(F(" SP=")); Serial.println(setpoint);
      } else if (buf == "STOP") {
        drive(0); Serial.println(F("OK STOP"));
      }
      buf = "";
    } else {
      buf += c;
    }
  }
}

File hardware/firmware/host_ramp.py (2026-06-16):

#!/usr/bin/env python3
"""
Stream a compiled anneal ramp to the thermocycler firmware over serial.

The compiler writes the ramp into <outdir>/design.json (key "anneal_ramp": list of
[tempC, minutes]). This host script reads it and sends one STEP command per row,
so the physical block runs exactly the ramp the protocol printed.

    pip install pyserial
    python host_ramp.py --design ../../examples/out_cube/design.json --port COM3

With --dry-run it prints the commands without needing the hardware (useful to check
the wiring of software -> protocol -> firmware).
"""
from __future__ import annotations

import argparse
import json
import sys
import time


def load_ramp(design_path):
    with open(design_path, "r", encoding="utf-8") as fh:
        d = json.load(fh)
    meta = d.get("meta", d)
    ramp = meta.get("anneal_ramp")
    if not ramp:
        raise SystemExit("no anneal_ramp in design.json")
    return ramp


def main(argv=None):
    ap = argparse.ArgumentParser()
    ap.add_argument("--design", required=True, help="path to compiled design.json")
    ap.add_argument("--port", default=None, help="serial port, e.g. COM3 or /dev/ttyUSB0")
    ap.add_argument("--baud", type=int, default=115200)
    ap.add_argument("--dry-run", action="store_true")
    a = ap.parse_args(argv)

    ramp = load_ramp(a.design)
    total_min = sum(m for _, m in ramp)
    print(f"[host] {len(ramp)} steps, ~{total_min/60:.1f} h total")

    if a.dry_run or not a.port:
        for t, m in ramp:
            print(f"STEP {t} {int(m*60)}")
        if a.dry_run:
            return 0
        print("[host] no --port given; dry listing only", file=sys.stderr)
        return 0

    try:
        import serial  # type: ignore
    except ImportError:
        raise SystemExit("pip install pyserial to drive the hardware")

    with serial.Serial(a.port, a.baud, timeout=5) as ser:
        time.sleep(2)  # board reset
        for t, m in ramp:
            cmd = f"STEP {t} {int(m*60)}\n"
            ser.write(cmd.encode())
            print(f"[host] -> {cmd.strip()}")
            # wait for DONE
            while True:
                line = ser.readline().decode(errors="ignore").strip()
                if line:
                    print(f"[fw]  {line}")
                if line == "DONE":
                    break
        ser.write(b"STOP\n")
    print("[host] ramp complete")
    return 0


if __name__ == "__main__":
    raise SystemExit(main())

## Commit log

2026-06-16 Molecular Synth v0: DNA self-assembly nanofab compiler + rig (+ Drink Synth)
    A desktop blueprint that programmably manufactures atomically-precise DNA-origami
    nanostructures: an AI compiler (shape -> scaffold + optimized staples + wet-lab
    protocol + relaxable 3D oxDNA structure) and a sub-1500-dollar rig from repurposed,
    orderable parts. Every capability cites a demonstrated paper; a validate gate enforces
    sourceable-AND-demonstrated. Includes an honest, simulation-only north-star track and
    Drink Synth, the buildable-today instance of the synthesizer thesis.
    [gel_box.scad, octahedron.stl, staples.csv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]
2026-06-16 Clear issues: PLY input, oxDNA relax inputs, Mg2+ screen, contributor docs
    - PLY mesh input (DAEDALUS/PERDIX format) + example tetrahedron.ply + test (closes #5)
    - Emit ready-to-run oxDNA min->relax input files (force-capped backbone resolves the
    vertex-junction stretch in the starting conf.dat) (closes #2)
    - Auto-emit the per-design MgCl2 x ramp folding screen as screen.md (closes #9)
    - CONTRIBUTING.md, issue/PR templates, ROADMAP.md (closes #10)
    [staples.csv, tetrahedron.ply]
2026-06-16 Add Water Synth (atmospheric water generation) + author note
    Water Synth: "a glass of drinkable water on demand" -> harvest water from AIR by Peltier
    condensation (atmospheric water generation) + activated-carbon filter + UV-C -> set
    temperature -> dispense. Same request-compiler pattern as drinksynth/molsynth; reuses the
    molecular rig's Peltier; cited (Kim et al., Science 356:430, 2017). Honest scope: harvest
    + treat, NOT matter-from-energy. The two-senses-of-water distinction (E=mc^2 materialise =
    north-star vs harvest+treat+dispense = real today) is documented in docs/vision.md.
    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
2026-06-16 Add the-ladder.md: the demonstrated research staircase DNA -> molecular manufacturing
    Answers "if we can figure out DNA, we can figure out this" honestly: maps the real,
    cited staircase from DNA origami (rung 0, on our desk) through DNA breadboards,
    DNA-templated synthesis, DNA robots, and artificial molecular assemblers (Leigh 2013/2017)
    up to general molecular manufacturing (rung 6+, north-star, not demonstrated). Every rung
    0-5 has a peer-reviewed lab demonstration; the honest gap is generality/scale/speed, not
    magic. Linked from vision.md and README.
2026-06-16 Rung 2: functional handle staples (DNA as a breadboard)
    Adds --decorate N: extends N spread-out staples with orthogonal single-stranded handles
    that protrude from the folded origami at known sites, and emits decoration.md -- a map of
    each handle + the anti-handle to conjugate to a guest (enzyme/catalyst/nanoparticle/dye)
    so it docks at that nm-precise position. The demonstrated first chemistry-capable rung
    (Fu et al. JACS 2012 enzyme cascades; Kuzyk et al. Nature 2012 nanoparticles).
    - decorate.py: orthogonal-handle generator + decoration map emitter.
    - Staple gains handle/spacer/guest + order_seq; binding region `seq` UNCHANGED so
    scaffold-complementarity (chem validity) is preserved and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
    [staples.csv]
2026-06-16 Rung 2 depth: cascade-aware handle placement (toward rung 3)
    --cascade "GOx,HRP": places an ORDERED enzyme cascade at a target nm spacing computed
    from the compiler's 3D structure (cascade efficiency is distance-dependent; Fu et al.
    JACS 2012). decoration.md reports the actual measured inter-enzyme distance at each site.
    - decorate.py: site_positions_nm() (3D site coords) + decorate_cascade() greedy chain at
    --cascade-spacing-nm; decoration.md gains a spacing column for cascades.
    - CLI: --cascade, --cascade-spacing-nm. Tests for ordering + measured spacing. Docs.
    [staples.csv]
2026-06-17 Maker Catalog + NL order brain + system-integration blueprint
    - catalog/: the Maker Catalog = the MENU of what the synth can make. Every item
    decomposes (item -> components -> molecules -> atoms; DNA where biological), gets a
    feasibility verdict (ready/assemble/frontier), and routes to a maker. Per the scoping
    rule, things the synth CANNOT make (a phone, matter from energy) are NOT catalog items;
    the checker still recognises + honestly declines them (-> docs/north-star.md).
    - order brain (makerlib/order.py + cocktails.json): natural language -> cross-maker plan.
    "whiskey on the rocks" -> ICE (watersynth) + POUR whiskey (drinksynth). Resolves slang
    + modifiers (on the rocks/neat/u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
2026-06-17 Add /proofs: "would it work IRL, given the parts?" - evidence, not assertions
    Six runnable proofs that move designs from "designed" to "proven sound given the BOM":
    - Staple addressing: every emitted oligo is the exact reverse complement of its scaffold
    region and the set tiles the scaffold exactly once (0 gaps/overlaps) - proven by algebra.
    - Thermodynamics: our SantaLucia Tm agrees with an INDEPENDENT tool (Biopython Tm_NN,
    DNA_NN3) within ~3 C - the engine is correct, not just self-consistent.
    - 3D structure: the emitted conf.dat independently re-parses as valid oxDNA (15-col,
    orthonormal frames) with B-DNA geometry (backbones outside, bases meet) - relaxable.
    - Thermocycler control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
2026-06-17 Core: face-aware A-trail routing (rotation-system bias)
    Routing now derives the face rotation system from the mesh and biases Hierholzer to
    "turn to the next edge" at each vertex (the A-trail rule), so the scaffold traces faces
    and avoids vertex crossings - while still guaranteeing a single Eulerian circuit (no loss
    of the single-scaffold guarantee). Meshes without faces fall back to arbitrary order.
    Upgrades the prior "simplified, non-face-respecting" routing to face-aware A-trail-style
    (Benson 2015). Adds a rotation-system test; doc wording corrected.
    [staples.csv]
2026-06-17 Core: off-target / scaffold-repeat screen in the optimizer
    M13mp18 has >100 repeats >=8 nt (the addressability ceiling; Nguyen et al.). The compiler
    now builds a repeat mask over the full scaffold and the optimizer penalises staples whose
    binding region contains a long contiguous scaffold-repeat, so break points split repeats
    across staples (reducing off-target binding). Per-staple off-target length is reported in
    staples.csv, the diagnostic, and staple_stats. Pure-stdlib; tests added.
    [staples.csv]
2026-06-17 Core: default the scaffold-rotation search (big yield-objective + Tm-uniformity win)
    Measured: searching M13 start offsets (scaffold is circular, so the start is a free
    design choice) roughly HALVES the optimizer objective (e.g. cube 144 -> 64) and tightens
    Tm spread (~6.3 -> ~3.9 C) and lowers off-target. Offset 0 is a poor window. So
    --scaffold-search now defaults to 4 (cheaper per-offset search: iterations//6). Use 1 to
    disable. Examples regenerated.
    [staples.csv]
2026-06-17 Core: near-free scaffold search via even-partition proxy (faster + more offsets)
    Replaced the per-offset full-SA build in the scaffold-rotation search with proxy_score():
    a single even-partition objective eval (the offset's intrinsic Tm/repeat quality is
    captured by the even partition). Same final objective (~64 on cube) while searching 8
    offsets instead of 4, and faster overall (tests 27s -> 19s; a full compile ~7s). Default
    --scaffold-search bumped to 8. Tests added.
    [staples.csv]
2026-06-17 Core fix: cube preset faces were inconsistently wound, corrupting the A-trail rotation
    The _cube() faces had mixed winding (3 outward/3 inward), so _rotation_system produced a non-permutation at 6/8 cube vertices and the face-aware A-trail bias silently degraded for the cube (routing stayed topologically valid, so nothing warned). Rewound all 6 faces consistently outward; the rotation test now covers tetra+cube+octa (was octahedron-only, which sidestepped the bug). Found by adversarial review.
    [staples.csv]
2026-06-17 Core robustness: consistently orient loaded STL/PLY/JSON faces (A-trail for real meshes)
    orient_faces() propagates a consistent winding across the face-adjacency graph (adjacent faces must traverse a shared edge in opposite directions; flip otherwise). Applied to load_stl/load_ply/load_json_spec so arbitrary real-world meshes - which are routinely inconsistently wound - get a clean rotation system and correct face-aware A-trail routing, generalising the cube-winding fix. Test added.
2026-06-17 Add browser 3D sim of the water module + GitHub Pages deploy
    web/index.html: self-contained Three.js sim proving a clean glass of water dispenses in seconds - valve-fed from a treated, pre-chilled buffer (carbon filter + UV-C >=40 mJ/cm2, the 4-log bacteria st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
2026-06-17 docs: molecule-vs-element.md - honest answer to 'CRISPR for molecules / carbon to oxygen'
    Element change (C->O) = nuclear transmutation (hard physics wall, north-star); molecule building (CO2->ethanol) = chemistry (real, frontier); the programmable tool = engineered enzymes/assemblers (fr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
2026-06-17 Rebuild GitHub Pages site: project showcase + in-page Blueprint (parts + build) + SEO
    Replaced the water-cooler sim with a proper multi-tab showcase: Overview (rotating DNA double-helix hero, key stats), What it makes (flagship nanofab + honest makers), Blueprint (live parts table fetched from the single-source bom.json with rig/consumable totals + the 8 build phases in-page), and The vision (feasibility ladder + molecule-vs-element). Added SEO meta (description, keywords, OG/Twitter cards). pages.yml stages bom.json into the site and redeploys on BOM changes. Repo description, homepage URL, and topics set for SEO.
2026-06-17 Plus ultra: live in-browser Synthesizer console on the Pages site
    web/synth.js is a faithful JS port of catalog/makerlib (order brain + catalog checker): type a request -> decompose -> honest feasibility verdict -> route to a maker -> machine plan, and DECLINE what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
2026-06-17 Ship printsynth: the 3D-print maker (objects join what the synth makes) — closes #8
    synth/printsynth: STL -> print job (mesh volume -> material + settings + filament/time/cost estimate + build-volume fit check + slicer hand-off). Honest: a standard FDM printer + free slicer does the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
    The synth's repertoire grows: drinks, water, nanostructures, and now physical objects. Always climbing.
2026-06-17 Live 3D nanostructure on the site: octahedron with DNA-double-helix edges
    The 'What it makes' tab now renders a rotating DNA-origami wireframe (each edge a real double-helix of base-paired spheres) so visitors SEE the atomic-precision output, not just read it. Showcases th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
2026-06-17 Fabrication-grade bridge: emit shape.ply (PERDIX/DAEDALUS hand-off)
    The compiler now writes the input mesh as shape.ply, the format the reference automated wireframe-design tools (PERDIX/DAEDALUS/TALOS/ATHENA) consume — the honest path to a production crossover geome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
    [shape.ply]
2026-06-17 Expand shapes: add the icosahedron preset (12v/30e/20f nanocage)
    The nanofab now folds an icosahedron - a 30-edge icosahedral nanocage (viral-capsid geometry, ~100 staples), demonstrating the compiler scales beyond toy shapes. Consistently oriented via orient_face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
    More shapes it can make = more it provably makes. Climbing.
    [shape.ply, staples.csv]
2026-06-17 Complete the Platonic set: add the dodecahedron preset (dual of the icosahedron)
    The nanofab now folds all five Platonic solids. The dodecahedron (20v/30e/12 pentagons, ~100 staples) is built as the DUAL of the verified icosahedron (vertices = icosa face-centroids; each pentagon = the face-ring around an icosa vertex in rotation order), so the topology is guaranteed correct - no hand-typed face list. Tests (20/30/12, pentagons, rotation, compile) + CLI + example.
    [shape.ply, staples.csv]
2026-06-17 core: machine-check the single-scaffold-circuit invariant + dimer-aware offset search
    The whole design rests on one physical premise: a single M13 strand threads the
    entire shape and returns to itself, laying down both duplex strands of every edge.
    Hierholzer guarantees this on the balanced doubled graph, but it was only asserted
    in prose. Now scaffold.circuit_report() verifies it (contiguous + closed + complete
    + balanced) and route() raises if a routing ever fails it -- a broken trail means an
    unmanufacturable teleporting scaffold, so we fail loudly before laying down sequence.
    - scaffold.py: circuit_report(arcs, edges); route() gates on it; Routing.single_circuit
    - __init__.py: surface s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
2026-06-17 core: measure + self-report A-trail routing quality (honest, not claimed)
    Issue #1. The prose called the routing "face-aware A-trail-style," but it was never
    quantified. Measured it: the rotation-biased Hierholzer follows a face boundary at only
    ~58-65% of vertex passages on the Platonic presets -- a real, bounded number, not a
    perfect A-trail. (A single Eulerian circuit can't reach 100%: it must deviate at >= F-1
    vertices to merge the F face loops into one strand.)
    Tried two constructors to beat it before shipping anything -- a spanning-tree face-merge
    (Veneziano-style) and a rotationally-nearest fallback. Both gave a valid single circuit
    but NEITHER reduced crossings vs greedy (some shape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
2026-06-17 export: caDNAno v2 JSON (-> CanDo / oxDNA), verified by an independent decoder
    Issue #3. Real interoperability: caDNAno is the most widely used origami CAD and the
    entry point to the CanDo finite-element shape/flexibility predictor and several oxDNA
    converters. Every compile now emits design_cadnano.json -- one virtual helix per scaffold
    segment; the scaffold threads helix 0->1->...->0 as one closed loop (M13 is circular),
    each staple on the antiparallel staple strand, crossing helices wherever it bridges a
    vertex, with the caDNAno [5'vh,5'idx,3'vh,3'idx] pointer 4-tuples.
    Honesty: I can't run the caDNAno GUI to confirm it loads, so I do NOT claim that. Instead
    cadnano_decode() independentl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
2026-06-17 core: tighten staple Tm uniformity via a guarantee-preserving equalize pass (#6)
    After simulated annealing settles the staple cut positions, run a deterministic
    hill-climb (equalize_tm) that nudges cuts ONLY to lower the per-staple Tm stdev --
    the cooperative-annealing lever for high origami yield (Aksel 2024). Every move is
    gated to preserve all hard guarantees: staple lengths stay in [len_lo, len_hi],
    crossover-boundary coverage never drops, loop-closure overload never rises, and
    off-target overload never rises. So it can only tighten (or hold) the spread.
    Measured effect (iterations=2000, offset 0):
    octahedron Tm stdev 6.37 -> 5.30 C (-1.07)
    cube Tm stdev 6.37 -> 5.30 C (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
2026-06-17 core: searched A-trail routing -> production-grade, near-zero vertex crossings (#1)
    The router now picks the scaffold circuit that minimises TRUE vertex crossings --
    passages that turn to a non-ADJACENT edge in the planar rotation (those force the
    strand over itself, strain the junction, and lower fold yield; Benson 2015). The prior
    metric counted only rotation-SUCCESSOR turns, which wrongly flagged predecessor turns
    (equally non-crossing) as crossings and led to a bogus "must deviate at >= F-1 vertices"
    floor in the diagnostics. Correcting the metric AND searching for it (deterministic,
    seeded multi-restart of the rotation-respecting Hierholzer; keep the fewest-crossing
    single circuit) coll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
2026-06-17 synth: add Item Synth -- the request-router front door for the maker federation
    The thesis is "ask for X -> an AI request-compiler routes it to the right cheap desktop
    maker." The makers existed (water, drink, print, molecular) but nothing unified them, so
    the thesis wasn't actually embodied -- you had to know which maker to call. itemsynth is
    that missing front door:
    from itemsynth import route
    route("a large glass of cold water") -> water maker recipe
    route("iced oat latte, large") -> drink maker recipe
    route("a phone case") -> print maker job
    route("an octahedron DNA nanocage") -> molecular compiler (emits a real design)
    route("a working smartpho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
2026-06-17 proof: validate compiled designs against published wireframe-origami envelopes (#7 digital half)
    The strongest software answer to "would this actually fold?" is: does it match the
    parameters of structures that ALREADY folded? New proof + test check every preset against
    the demonstrated, cryo-EM/AFM-verified envelopes of Veneziano 2016 (DAEDALUS, Science
    352:1534) and Benson 2015 (Nature 523:441):
    - edges on integer helical turns -> in-phase crossovers (measured phase error 0.00 bp;
    63 bp = exactly 6 x 10.5)
    - every edge >= 31 bp (DAEDALUS minimum) and >= 10 nm
    - staple lengths in the synthesizable + bindable 21-78 nt band
    - scaffold usage <= M13 (7249 nt)
    All five Platonic prese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
2026-06-17 core: surface crossover-phase quality in diagnostics (DAEDALUS in-phase credential)
    Measures, per design, how far the worst edge sits from an integer number of 10.5-bp
    helical turns -- the DAEDALUS rule that keeps the two helices of each wireframe edge in
    register so crossovers don't slip. The compiler already snaps edges to integer turns, so
    regular meshes report 0.00 bp (perfectly in-phase); the diagnostic now shows this where
    the user sees it, with an honest verdict (off-phase edges -> relax in oxDNA). Added as
    design['crossover_phase_max_bp'] + a line in the routing block.
    Investigated tightening the 3D vertex geometry too: measured the residual vertex-junction
    stretch (~2.6 oxDNA units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
2026-06-17 fix: keep equalize_tm only when it improves the FULL objective (it was degrading yield)
    Found by experiment ("surprise myself"): the equalize_tm post-pass I shipped for issue #6
    was accepted on Tm-stdev improvement alone, and anneal() then overwrote best_score with the
    refined score even when it was WORSE. Measured across tetra/cube/octa/square x 3 seeds, this
    degraded the optimizer's own predicted-yield objective in 12/12 small-shape cases (+4..+9),
    helping only the two largest presets. Cause: tightening Tm STDEV is one term; pushing it
    past the model's optimum raises the Tm-WINDOW penalty (staples driven out of [tm_lo,tm_hi])
    by more than the variance penalty falls. Since Tm variance is AL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
2026-06-18 refactor: unify the federation behind one front door (itemsynth)
    The thesis promises "all behind one front door, Item Synth," but the Maker Catalog
    (catalog/makerlib) was a second, disconnected entry. Wire it in as an ENGINE of the one
    front door instead:
    - orchestrate.py: synthesize() (smart entry: route a single maker, north-star verdict, or
    fall back to the catalog so "whiskey on the rocks" -> ice + pour resolves), plus
    feasibility() and plan() delegating to makerlib.checker / makerlib.order.
    - ensure_federation_paths(): the single import seam now bridges all three roots
    (synth/ + compiler/ + catalog/), replacing scattered sys.path hacks.
    - CLI default is now synthesize; --feasibil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
2026-06-18 research: molecular-level study of the compiler (4 reproducible experiments + findings)
    exp1 Tm validation + buffer salt calibration: molsynth NN Tm matches Biopython DNA_NN3 to
    mean|dT|=0.86C (implementation correct), but the na_M=50mM default under-predicts the
    12.5mM-Mg folding-buffer Tm by ~9C; buffer-accurate [Na+]_eq ~= 166mM (the docstring's
    120*sqrt[Mg]=13mM rule is ~22C low). Owczarzy 2004/2008 ground truth.
    exp2 scale physics ("build molecules but bigger?"): forces are not scale-invariant -
    gravity overtakes thermal at ~0.79um; a 50nm origami self-transports 4.2um/s, an apple
    4nm/s. Manipulation/self-assembly sweet spot ~10nm-0.8um == the DNA-origami window. Path
    molecu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
2026-06-18 science: physics/materials red-team -> ship reality-check diagnostics
    Audited the END PRODUCT like code (research/exp6): the physical assumptions that break the
    real folded object even when compile_shape() succeeds. Findings (over 11 committed designs):
    F1 HIGH single-duplex wireframe edges are floppy: every edge ~63bp -> RMS thermal bend ~38
    deg (worm-like chain, Lp~50nm). Stiffness is a design variable (multi-helix bundles).
    F2 HIGH Tm mis-calibrated for the 12.5mM-Mg buffer (~+9C; exp1).
    F3 MED G-quadruplex sequestration unscreened (audit: 490 staples -> 0 motifs, clean today).
    F4 MED objective is thermodynamic; folding is kinetic (no assembly-order term).
    Shipped (additiv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
2026-06-18 docs: refresh READMEs/roadmap/theory for the federation + research, improve readability
    - README: add research/ to the box; reality-check diagnostics + federation front door in
    Status; fix stale test count (13 -> 50 compiler tests).
    - ROADMAP: record the shipped federation refactor + measured research study + reality-check
    diagnostics; list the 4 physics-backed compiler upgrades honestly as in-progress (not merged).
    - compiler/README: document the Physics & materials reality check + tm_buffer/G4/WLC; fix test count/time.
    - vision: all four makers behind one front door; add the scale-physics grounding for why nano is tractable.
    - the-ladder / north-star: cross-ref the scale-physics findin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
2026-06-18 compiler: integrate 4 verified physics rungs (stiffness dial, kinetic ladder, hierarchy sim, Tm recalibration)
    From the parallel implement+adversarial-verify workflow; all four are molecular, so all survive
    the molecular-only refocus. Each was verified (physics sound, tests meaningful, no overclaim).
    - STIFFNESS AS A DIAL (mechanics.py + edge_helices param): a calibrated bundle-beam model maps
    (edge_bp, n_helices) -> effective Lp + RMS thermal bend. Single duplex anchored at Lp=50nm
    (= wlc_rms_bend_deg); 6-helix bundle calibrated to the measured ~5um (Kauert 2011). Diagnostics
    stiffness verdict now reflects helix count: default FLOPPY ~38deg, edge_helices=6 rigid ~4deg.
    Reports the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
